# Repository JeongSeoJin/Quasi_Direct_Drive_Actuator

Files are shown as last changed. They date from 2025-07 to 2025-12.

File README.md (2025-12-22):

<script type="text/javascript" async
  src="https://cdnjs.cloudflare.com/ajax/libs/mathjax/2.7.7/MathJax.js?config=TeX-MML-AM_CHTML">
</script>
<script type="text/x-mathjax-config">
  MathJax.Hub.Config({
    tex2jax: {
      inlineMath: [['$','$'], ['\\(','\\)']],
      displayMath: [['$$','$$'], ['\\[','\\]']],
      processEscapes: true
    }
  });
</script>

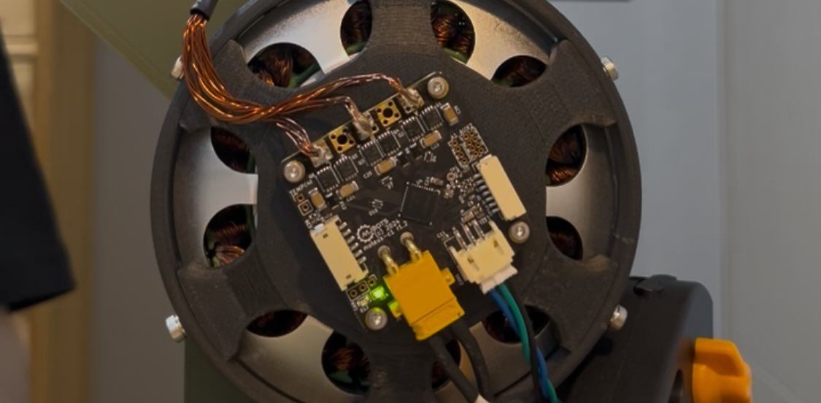
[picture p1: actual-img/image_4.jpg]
Actuator image 1


# Cycloidal QDD Actuator for Dynamic Robots

> *Note: This is an ongoing project. Please note that some sections, particularly '5. Control & Validation', are currently being documented. New test results and updates will be uploaded soon.*

[=> view this page in github with resources](https://github.com/JeongSeoJin/quasi-direct-drive-actuator)

Table of contents

- [1. Abstract](#1-abstract)
- [2. Actuator Design : Why Cycloidal QDD Actuator?](#2-actuator-design-why-qdd-actuator)
- [3. System Architecture & Components](#3-system-architecture--components)
- [4. Assembly](#4-assembly)
- [5. Control & Validation](#5-control--validation)
- [6. Limitations & Future Works](#6-limitations--future-works)
- [7. Credits](#7-credits)
- [8. References](#8-references)

---

## 1. Abstract
Rapid advancements in dynamic humanoid and quadruped robots have surged recently. However, high-performance actuators remain largely proprietary, restricting access for academic researchers and open-source communities. This project aims to democratize dynamic robotics by developing an open-source Quasi-Direct Drive (QDD) actuator tailored for mid-size humanoid robots.

Traditional high-ratio gearboxes suffer from poor back-drivability, low responsiveness and limited transmission transparency, making them unsuitable for safe Human-Robot Interaction (HRI) and uneven terrain locomotion. To address this, I propose a custom-designed QDD actuator featuring a 1:10 cycloidal reducer. This low-reduction architecture minimizes mechanical impedance, enabling back-drivable, high responsiveness and proprioceptive torque sensing via FOC algorithms without additional sensors.

The current prototype utilizes a 3D-printed and aluminium structure to ensure low cost and accessibility. Preliminary assessments estimate a maximum holding torque exceeding 7 Nm, with comprehensive performance verification currently underway. This work contributes to the robotic community by providing a scalable, affordable, and high-performance actuation solution.

  <table>
    <tr>
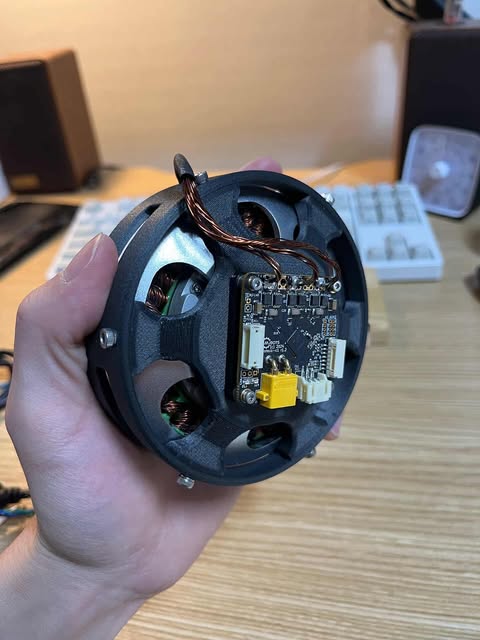
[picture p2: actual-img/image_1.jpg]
Actuator image 1
      <td></td>
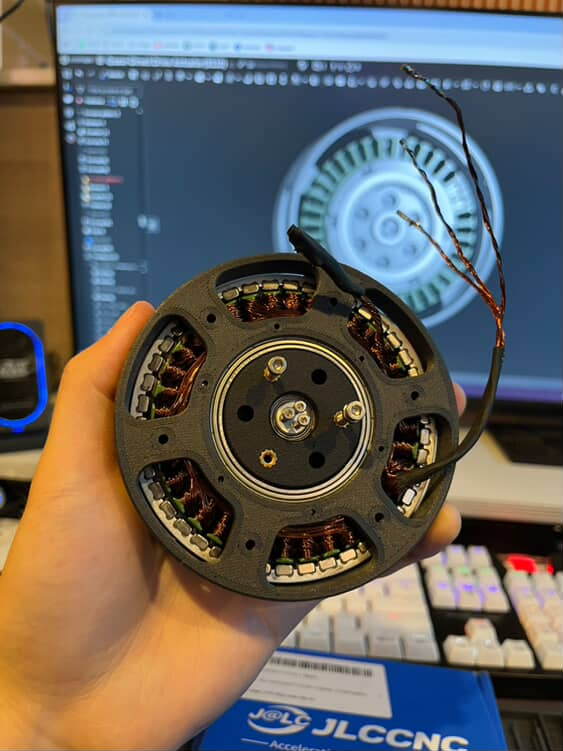
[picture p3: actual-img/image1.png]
Actuator image 2
      <td></td>
    </tr>
  </table>

---

## 2. Actuator Design: Why QDD Actuator?

### 2.1 The Limitations of Traditional Actuators

**Conventional robotic actuators** typically utilize high gear reduction ratios (e.g., 1:100 or higher) to amplify torque. However, this approach introduces significant drawbacks for dynamic robots.

A high gear ratio leads to **high mechanical impedance**, primarily due to increased friction and reflected inertia compared to low-ratio systems [[1]](#8-references).

This high impedance makes the motor response sluggish and susceptible to damage from sudden external impacts, as the actuators are too stiff to react compliantly. In other words, the actuator exhibits **poor back-drivability and low responsiveness**. Consequently, these properties hinder the robot's ability to interact safely with the environment, particularly in Human-Robot Interaction (HRI) scenarios or during dynamic locomotion.

As robots become more integrated into our daily lives, physical interaction and cooperation will become increasingly common. In these scenarios, traditional actuators pose a significant safety risk. Since robots with stiff actuators struggle to sense external forces [[2]](#8-references), they can unintentionally injure people due to their lack of compliance. Furthermore, regarding locomotion, such robots cannot flexibly adapt to unpredictable environments, such as rough or uneven terrain, leading to instability.

### 2.2 The QDD System Solution
To address these issues, I adopted a **Quasi-Direct Drive (QDD) architecture**. A QDD system typically features a low gear reduction ratio, ranging from 1:3 to 1:10. By positioning itself between Direct Drive (1:1) and traditional high-ratio drives (1:50 or higher), it combines the structural advantages of both systems.

The low gear ratio significantly minimizes friction and reflected inertia, rendering the actuator **inherently compliant**. This compliance ensures the system is smoothly back-drivable and highly responsive to external interactions, effectively mitigating the stiffness drawbacks of conventional actuators.

Consequently, this **improved back-drivability and responsiveness** enable the robot to safely interact with humans and flexibly adapt to uneven terrain during dynamic locomotion.

**At this point, a critical question arises:** "How can the actuator generate sufficient torque for dynamic motions with such a low gear ratio?" The following section details the design strategy used to resolve this trade-off.

### 2.3 Motor Design Optimization
To achieve high torque density suitable for a Quasi-Direct Drive (QDD) system, I focused on the geometric parameters of the motor. According to the motor design principles outlined in the MIT Cheetah research, the continuous torque generation capability ($\tau$) is approximated by the following equation:

$$\tau \propto \sigma \cdot l_{st} \cdot r_g^2$$

Where:
* **$\sigma$**: Shear stress density (magnetic flux density $\times$ current loading)
* **$l_{st}$**: Stack length of the motor
* **$r_g$**: Air gap radius

As shown in the equation, torque is linearly proportional to the stack length ($l_{st}$) but proportional to the **square of the air gap radius ($r_g^2$)**. This implies that increasing the motor diameter is significantly more efficient for boosting torque than increasing its length. Based on this principle, I selected a stator with a large diameter (8110 size) to maximize the air gap radius, thereby securing sufficient torque even with a low gear reduction ratio.

### 2.4 Transmission Selection: Why Cycloidal Reducer?

In dynamic legged locomotion, the actuator must withstand high impact loads caused by ground reaction forces. While **Harmonic Drives** are industry standards for zero-backlash precision, their flexible spline mechanism is notoriously fragile under shock loads.

Similarly, **Planetary Gearboxes**, though common, exhibit inherent backlash. It works well with aluminum gears, but becomes significantly fragile when 3D printed. In a 3D-printed planetary system, the stress concentrates on individual small gear teeth, making them prone to catastrophic failure under sudden external forces.

To ensure robustness, I selected a **Cycloidal Reducer** architecture. According to Sensinger's research, this mechanism distributes the load across multiple lobes simultaneously. This load-sharing capability provides significantly higher Shock Resistance compared to involute gears or fragile harmonic drives, making it the ideal candidate for a fully 3D-printed transmission [[3]](#8-references).

Furthermore, I optimized the internal mechanism for efficiency. While the outer profile uses a solid design for structural strength, the internal output mechanism operates based on Rolling Contact. By utilizing rolling pins for the output shaft transmission, I successfully minimized internal friction where structural fragility is less of a concern. This strategic design choice preserves the Back-drivability required for the QDD system while maintaining the robustness of the outer shell.

---

## 3. System Architecture & Components

### 3.1 Mechanical Design (Cycloidal Reducer)
A custom **Cycloidal Quasi-Direct Drive Actuator** is designed to ensure high torque density, compactness, and compliance.

I utilized Onshape 3D CAD to design a dual-disc cycloidal mechanism. The two cycloidal discs are arranged with a $180^\circ$ phase offset. This configuration effectively cancels out the radial forces and vibrations induced by the eccentric input shaft, ensuring smooth operation.

To maximize efficiency, I integrated rollers into the output pins. Unlike simple sliding contacts, these rollers minimize internal friction at the output stage, contributing to the system's back-drivability.

For the current prototype, the gears, shafts and rotor are manufactured from CNC-machined Aluminum to verify the design with a high strength-to-weight ratio. (Note: The final goal of this project is to optimize the design for a fully 3D-printed, low-cost actuator for dynamic robots.)

  <table>
    <tr>
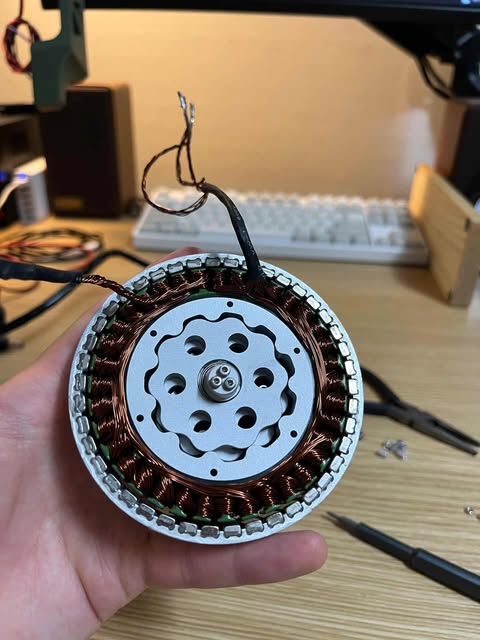
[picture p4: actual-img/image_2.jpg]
Actuator image 1
      <td></td>
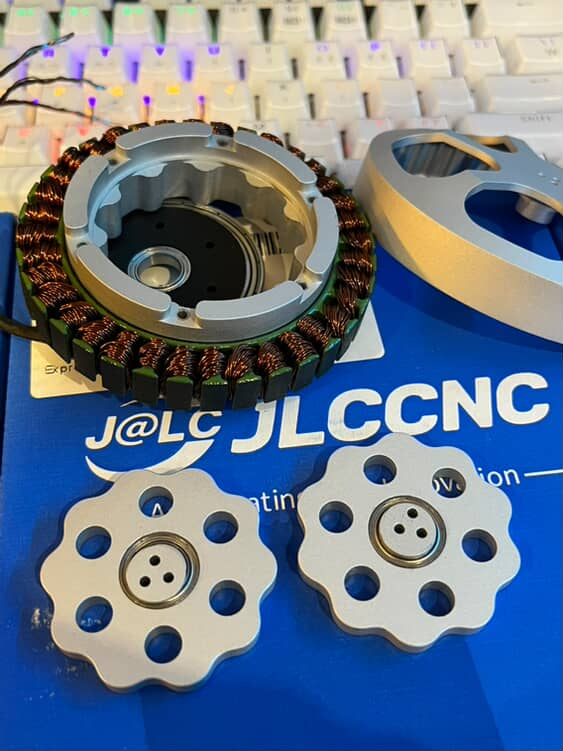
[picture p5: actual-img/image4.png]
Actuator image 2
      <td></td>
    </tr>
  </table>

### 3.2 Electromagnetic Design (Custom BLDC)

To optimize torque density within the compact housing, I integrated a **custom-built frameless Brushless DC (BLDC) motor** instead of using a standard motor.

For the stator, I utilized a standard 8110 stator core. To achieve the desired current capacity and fill factor, the stator was hand-wound using 0.4mm enameled copper wire. I applied a Wye (Star) termination with 6 parallel strands and 5 turns per tooth, following the optimal winding scheme calculated via open-source tools [[4]](#8-references).

The motor adopts a 36N42P configuration (36 slots, 42 poles) to maximize torque output. For the rotor, 42 N52-grade Neodymium magnets were installed. These magnets were precisely bonded using high-strength epoxy (JB Weld) in an alternating polarity pattern (N-S-N-S) to maximize magnetic flux density and ensure structural integrity under high rotation speeds. Crucially, the rotor geometry was optimized to achieve a minimal air gap of 0.5mm. This tight clearance maximizes the magnetic flux linkage between the rotor and stator, thereby significantly enhancing the electromagnetic force and overall torque efficiency.

### 3.3 Electronics & Sensors
For precise torque control and dynamic response, I integrated the **Moteus-c1 controller** (mjbots). This controller is widely adopted in the dynamic robotics community for its compact form factor and high bandwidth.

It implements **Field Oriented Control (FOC)**, which is essential for smooth torque generation and the proprioceptive capabilities mentioned earlier. With a wide input range (10-51V) and 20A peak phase current, it provides sufficient power capacity to drive the custom-wound 8110 stator to its full potential.

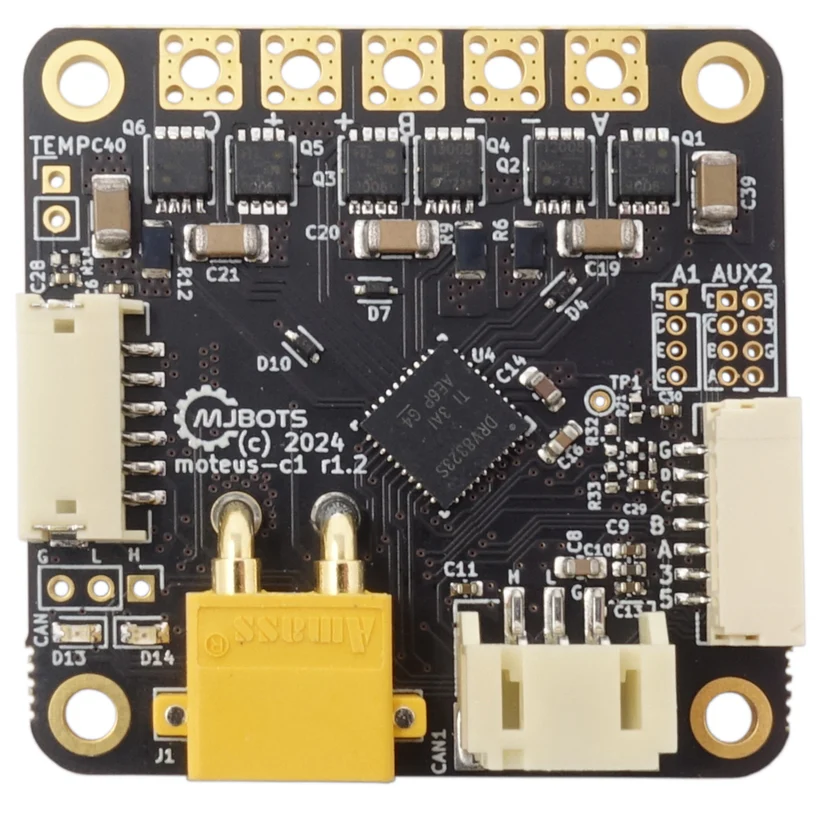
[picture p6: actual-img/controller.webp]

---

## 4. Assembly
Precise assembly is critical to minimize backlash and ensure the longevity of the reducer. I implemented distinct **tolerance strategies** based on the material properties of each component.

### 4.1 Bearing Installation & Fits
For the housing components printed in PA-CF12 (Carbon Fiber Nylon), I designed a 0.1mm interference fit. This accounts for the material's slight compliance and thermal shrinkage during printing, ensuring a secure press-fit without cracking the part.

Conversely, for the CNC-machined Aluminum parts, a tighter 0.02mm interference fit was applied due to the metal's rigidity. To prevent any micro-movements or slippage under high torque loads, I reinforced these metal-to-bearing interfaces with a thin application of JB Weld epoxy.

### 4.2 Output Mechanism
The output transmission relies on smooth rolling contact. I installed six M2x20mm stainless steel shafts to serve as the carrier pins. These shafts were precision-aligned to allow the external rollers to rotate freely, minimizing friction at the output stage while maintaining structural rigidity.

---

## 5. Control & Validation
preparing 

---

## 6. Limitations & Future Works
### 6.1 Limitations of the Current Prototype

Through the testing and assembly process, two primary limitations were identified regarding the actuator's performance and structural dynamics.

First, Suboptimal Magnetic Flux Path (Rotor Design)
The current rotor design does not incorporate a ferromagnetic back-iron or a Halbach array arrangement. Consequently, the magnetic flux is not effectively focused inward toward the stator, leading to flux leakage.

Since air-gap flux density directly correlates with torque generation, this lack of magnetic circuit optimization results in a lower torque density than theoretically possible. In future iterations, adding a steel back-iron will be essential to maximize torque output.

Second, Structural Rigidity of the Eccentric Shaft
The second issue lies in the assembly of the eccentric input shaft. Currently, it is constructed as a multi-part assembly fastened with bolts and nuts, rather than a single monolithic part. 

During operation, the strong radial magnetic attraction between the rotor and stator exerts significant force on the shaft. This force compromises the alignment of the multi-part shaft assembly, causing slight structural deflection. This misalignment leads to unwanted oscillation and vibration, particularly at higher rotational speeds. A monolithic (single-piece) shaft design is required to resolve this issue.

### 6.2 Future Works

Moving forward, I aim to integrate these custom QDD actuators into a mid-size bipedal robot to validate their performance in a complete system. The target platform will feature a total of 10 degrees of freedom (DoF), with 5 actuators allocated to each leg, specifically designed to handle dynamic walking tasks. This project will serve as a crucial step in verifying the scalability of my hardware design while providing a physical testbed for implementing advanced locomotion control algorithms.

---

## 7. Credits
* Design, Engineering and Documentation: [Seo Jin Jeong](https://jeongseojin.github.io/)
* Manufacturing Sponsor: [JLCCNC](https://jlccnc.com/)
* Motor Controller: [Moteus-c1 Controller (mjbots)](https://mjbots.com/products/moteus-c1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)
* Youtube : [Engineering SeoJin](http://www.youtube.com/@engineeringseojin)
* Instagram : [engineering.seojin_n.n](https://www.instagram.com/engineering.seojin_n.n?utm_source=ig_web_button_share_sheet&igsh=ZDNlZDc0MzIxNw==)

## 8. References

[1] S. Seok et al., "Design Principles for Energy-Efficient Legged Locomotion and Implementation on the MIT Cheetah Robot," in IEEE/ASME Transactions on Mechatronics, vol. 20, no. 3, pp. 1117-1129, June 2015, doi: 10.1109/TMECH.2014.2339013. 

[2] P. M. Wensing, A. Wang, S. Seok, D. Otten, J. Lang and S. Kim, "Proprioceptive Actuator Design in the MIT Cheetah: Impact Mitigation and High-Bandwidth Physical Interaction for Dynamic Legged Robots," in IEEE Transactions on Robotics, vol. 33, no. 3, pp. 509-522, June 2017, doi: 10.1109/TRO.2016.2640183.

[3] Sensinger, J. W. (February 9, 2010). "Unified Approach to Cycloid Drive Profile, Stress, and Efficiency Optimization." ASME. J. Mech. Des. February 2010; 132(2): 024503. https://doi.org/10.1115/1.4000832

[4] "bavaria-direct.co.za - Homebuilt Electric Motors," [Online]. Available: https://www.bavaria-direct.co.za/scheme/calculator/.

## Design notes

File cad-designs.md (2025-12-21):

## Overview

<div style="display:flex; flex-wrap:wrap; gap:8px;">
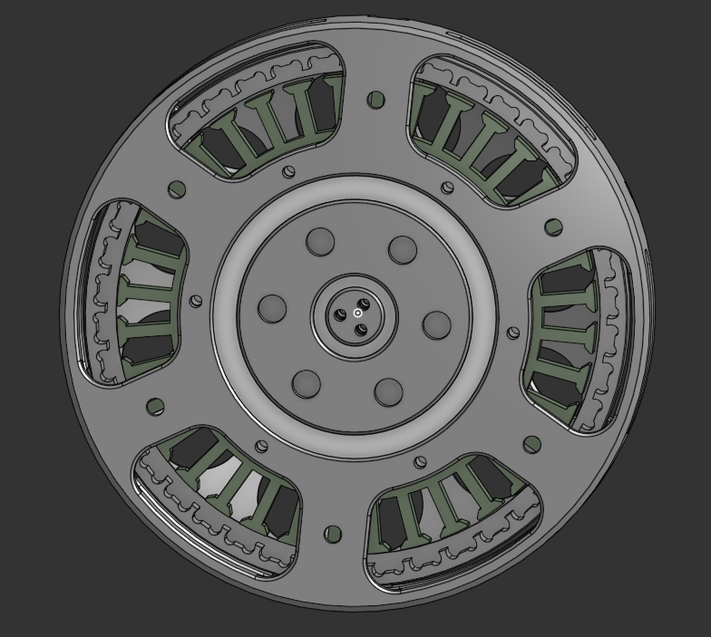
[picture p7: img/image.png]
overview1
  
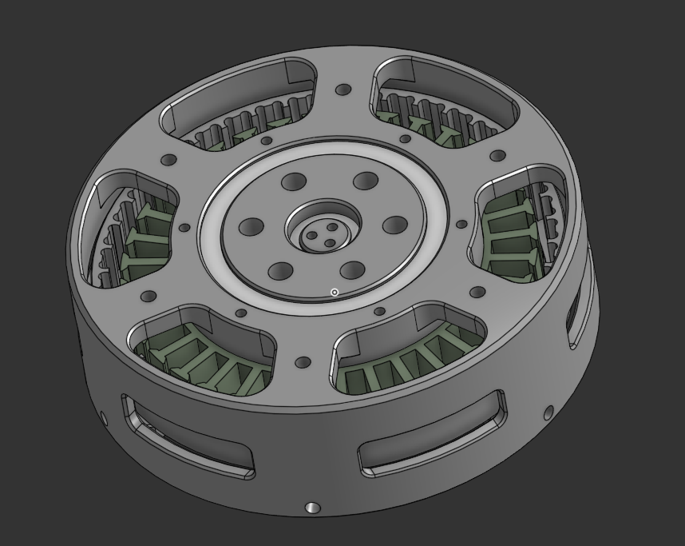
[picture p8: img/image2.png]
overview2
  
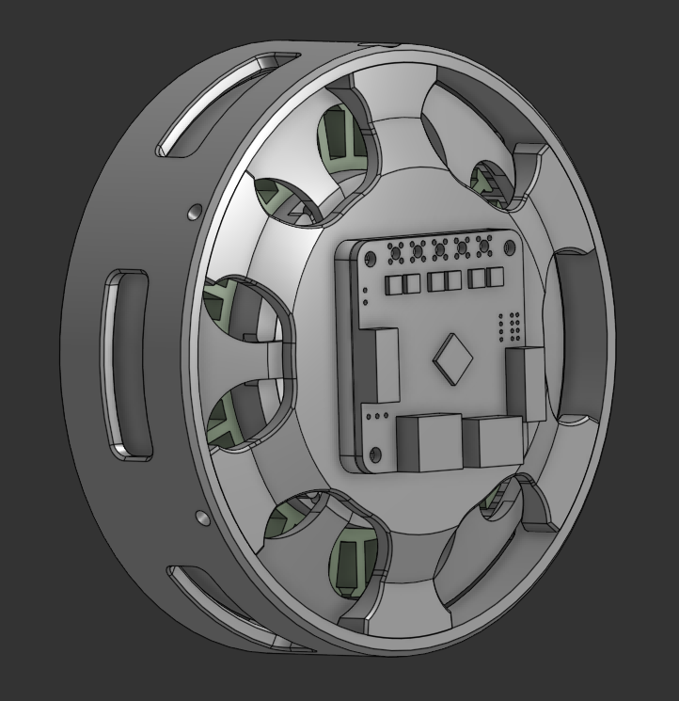
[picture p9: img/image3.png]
overview3
  
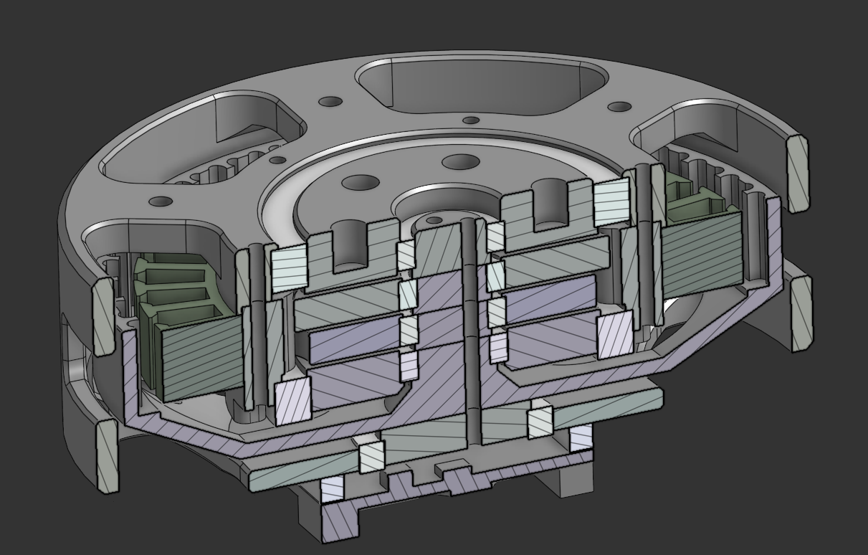
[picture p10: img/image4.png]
overview4
  
</div>

---

## Materials & finishes

### Housing — PA12-CF
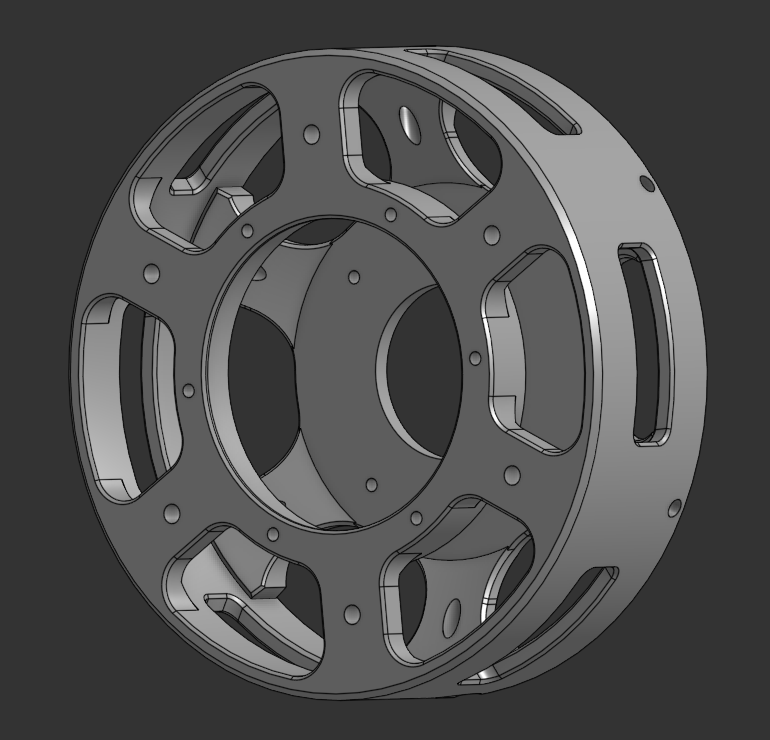
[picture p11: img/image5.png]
housing


### Gears — Aluminum 6061 (bead blasted + anodized)
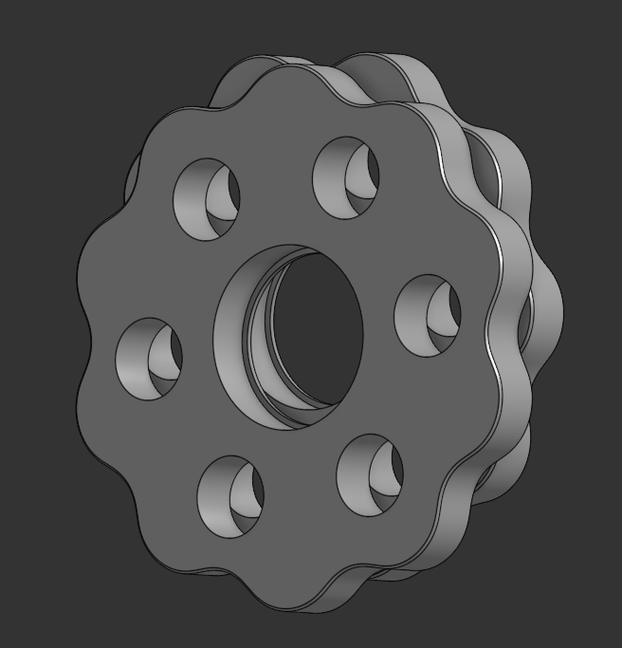
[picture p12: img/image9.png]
gears


### Input shaft & rotor — Aluminum 6061 (bead blasted + anodized)
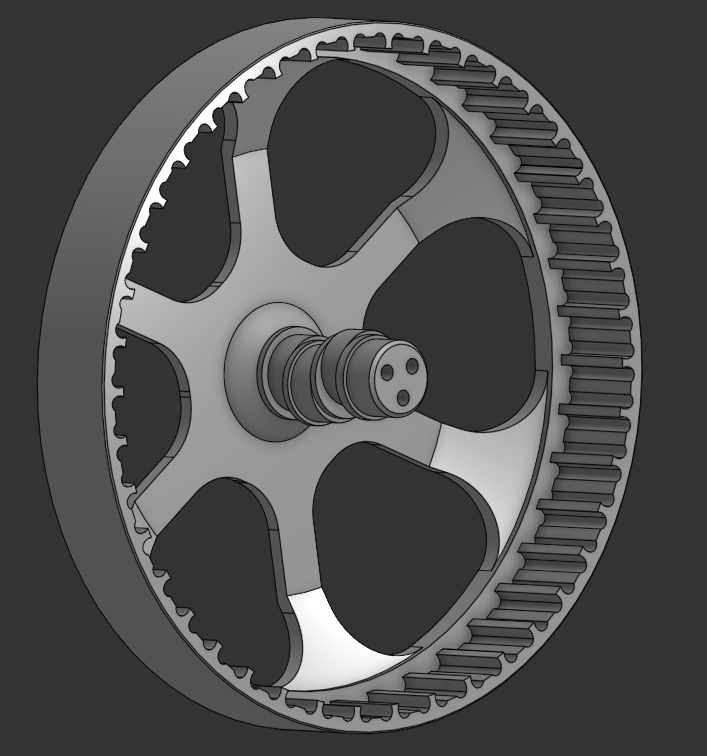
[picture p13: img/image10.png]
shaft1

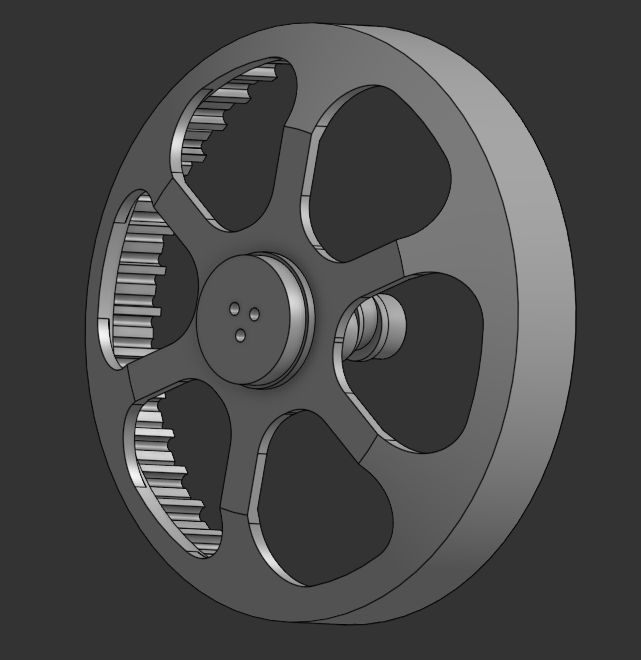
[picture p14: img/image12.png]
shaft2


### Output shaft — PA12-CF
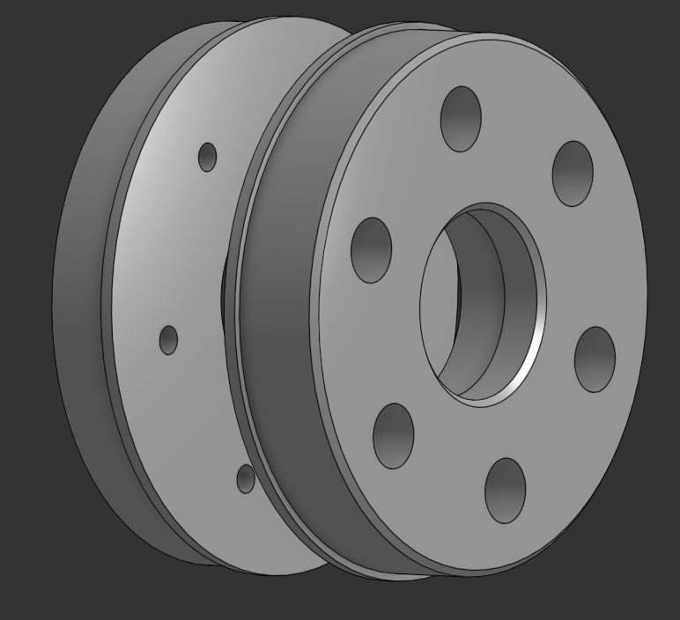
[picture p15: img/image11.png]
output-shaft


### Outer gear — PA12-CF or Aluminum 6061
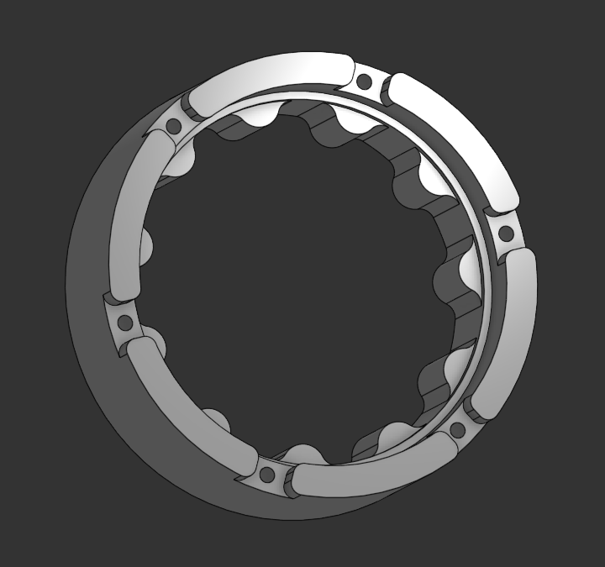
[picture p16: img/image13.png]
outer-gear


### Coupler — Housing to rotor(PLA)
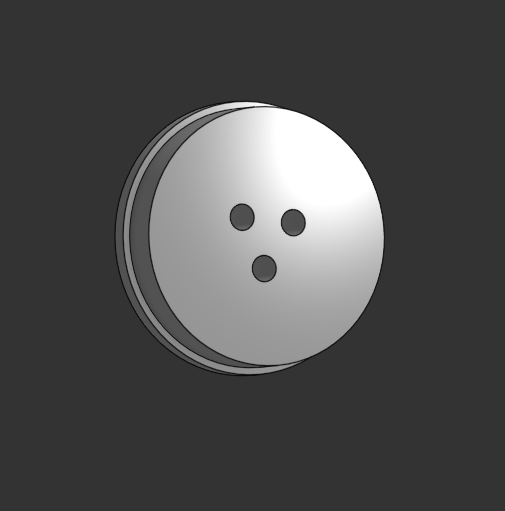
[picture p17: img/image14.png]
coupler


---

## Off-the-shelf parts
Common commercial parts used: bearings, stator, FOC controller, fasteners. See OFF_THE_SHELF_SPECIFICATIONS for part numbers and suppliers.

<div style="display:flex; gap:8px; flex-wrap:wrap;">
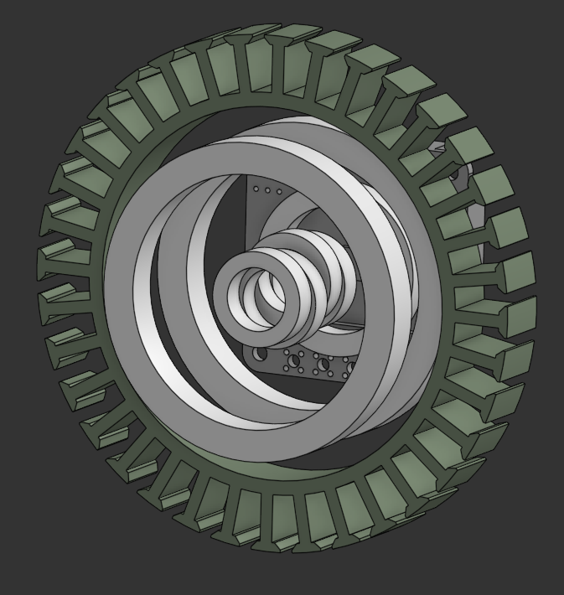
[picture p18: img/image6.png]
part1
  
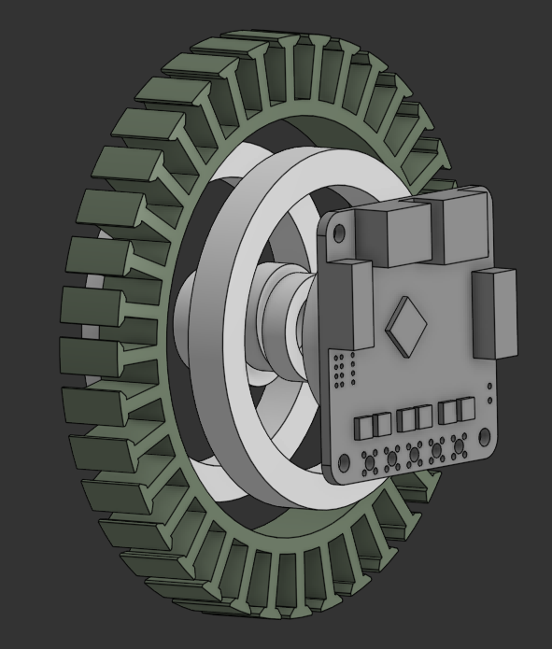
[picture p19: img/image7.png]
part2
  
</div>

---

## Assembly images
These are assembly images(I'm preparing for more details)

<div style="display:flex; flex-wrap:wrap; gap:8px;">
  assembly1
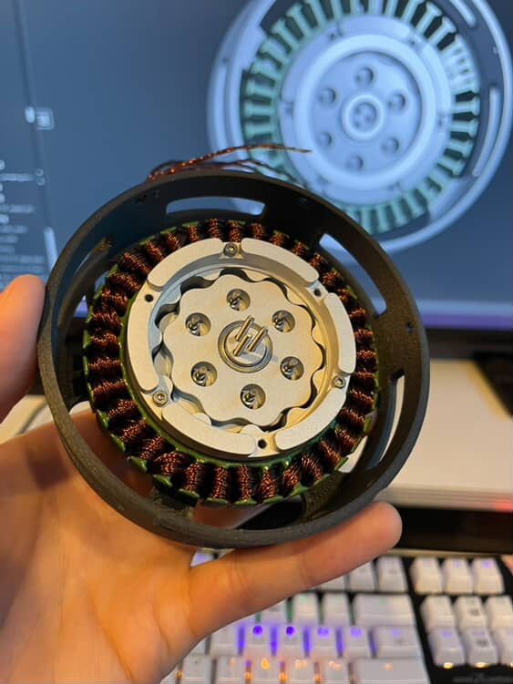
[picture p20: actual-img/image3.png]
assembly2
  
  assembly3
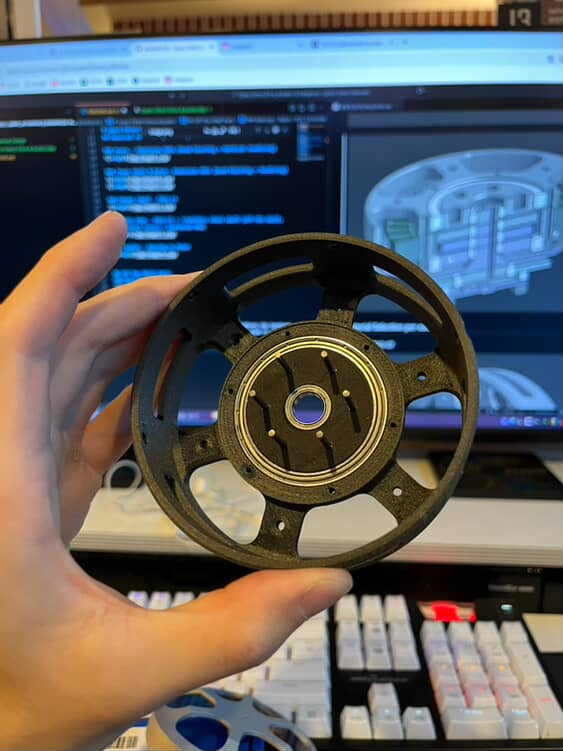
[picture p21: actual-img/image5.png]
assembly4
  
  assembly5
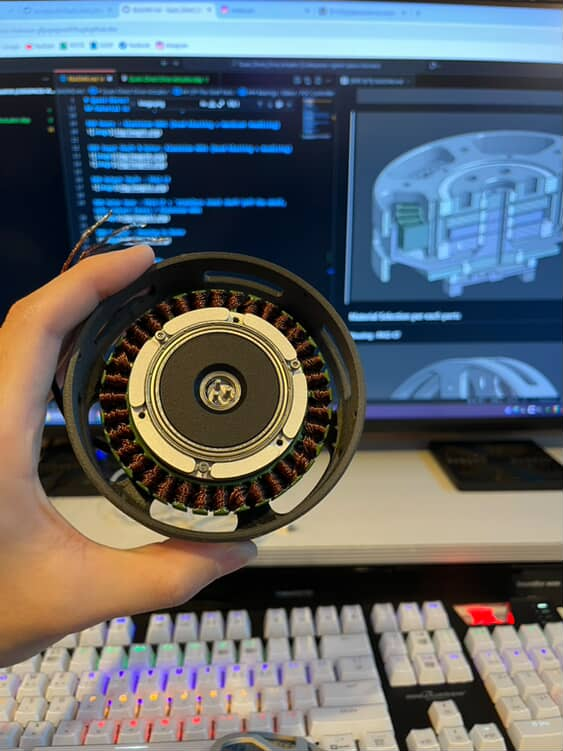
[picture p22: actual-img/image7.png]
assembly6
  
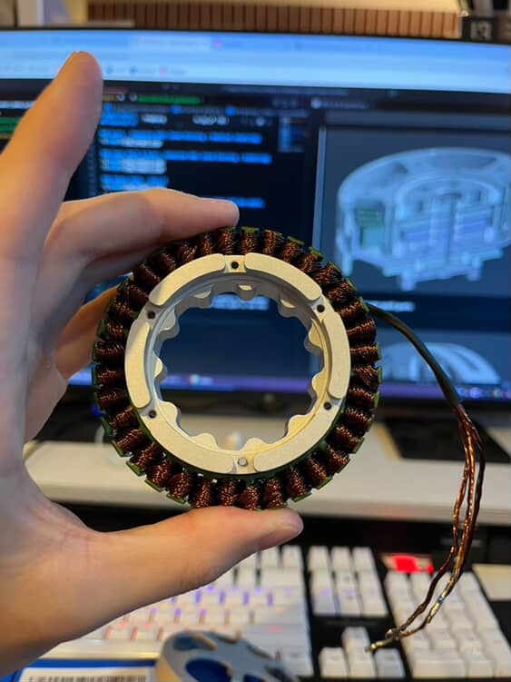
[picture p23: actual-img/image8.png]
assembly7
  
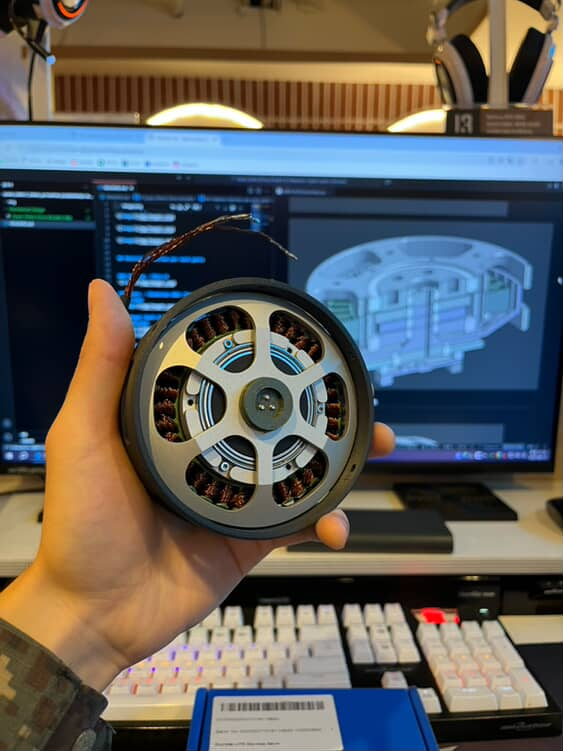
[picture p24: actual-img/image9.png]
assembly8
  
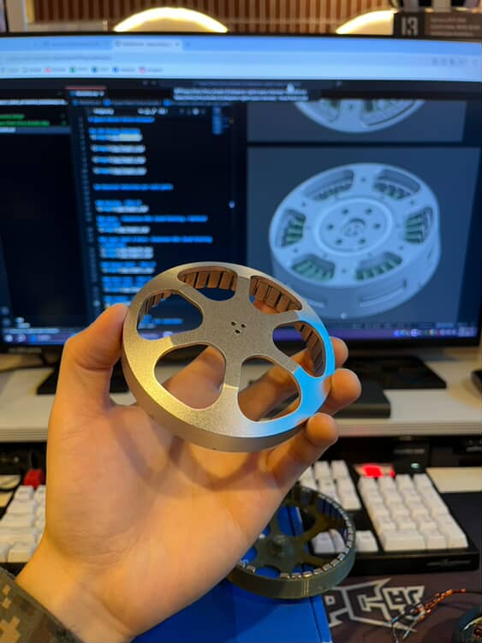
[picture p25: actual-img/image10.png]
assembly9
  
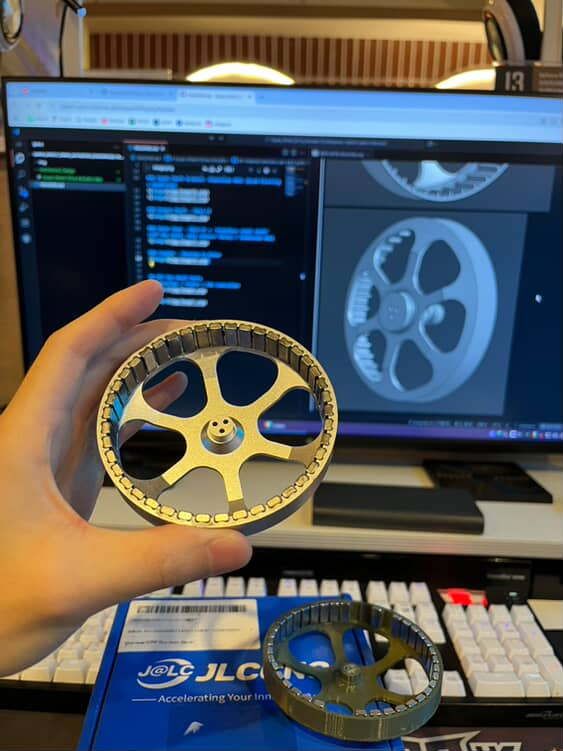
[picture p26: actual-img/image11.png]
assembly10
  
</div>

---

I keep developing my actuators. It's ongoing project. please stay tuned!

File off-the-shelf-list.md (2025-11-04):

# Off the shelf parts are listed in this file 

1. [8110 stator](https://ko.aliexpress.com/item/1005005460688806.html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) : (1EA)
2. [Bushing](https://ko.aliexpress.com/item/1005008259517878.html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) : D4xM2xL5(12EA)
3. [Shaft](https://ko.aliexpress.com/item/1005007023343232.html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) : M2, 20mm(6EA)
4. [Bearings](https://ko.aliexpress.com/item/4000909605390.html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,scm-url:1007.14452.398466.0,pvid:2f273fae-4f10-467f-b87d-71dfd033900c,tpp_buckets:668%232846%238108%231977&pdp_ext_f=%7B%22order%22%3A%22285%22%2C%22eval%22%3A%221%22%2C%22sceneId%22%3A%2230050%22%2C%22fromPage%22%3A%22recommend%22%7D&pdp_npi=6%40dis%21KRW%213466%211908%21%21%212.34%211.29%21%40210156fc17622595700133547e27dc%2112000028447926012%21rec%21KR%212150707868%21X%211%210%21n_tag%3A-29919%3Bd%3Ac599d003%3Bm03_new_user%3A-29895%3BpisId%3A5000000192578935&utparam-url=scene%3ApcDetailTopMoreOtherSeller%7Cquery_from%3A%7Cx_object_id%3A4000909605390%7C_p_origin_prod%3A&search_p4p_id=202511040432500535210504583292530167_0) : 40x50x6mm(2EA), 20x27x4mm(1EA), 10x15x4mm(4EA)
5. [Moteus Controller C1](https://mjbots.com/products/moteus-c1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) : (1EA)
6. [Enameled copper wire](https://ko.aliexpress.com/item/1005001704276751.html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,scm-url:1007.14452.398466.0,pvid:4f8f4469-c6f8-42d0-87eb-8b017c4bf703,tpp_buckets:668%232846%238108%231977&pdp_ext_f=%7B%22order%22%3A%2215%22%2C%22eval%22%3A%221%22%2C%22sceneId%22%3A%2230050%22%2C%22fromPage%22%3A%22recommend%22%7D&pdp_npi=6%40dis%21KRW%2121369%2117950%21%21%21102.83%2186.38%21%4021015b7d17622599050302774e0a10%2112000017224525099%21rec%21KR%212150707868%21X%211%210%21n_tag%3A-29919%3Bd%3Ac599d003%3Bm03_new_user%3A-29895&utparam-url=scene%3ApcDetailTopMoreOtherSeller%7Cquery_from%3A%7Cx_object_id%3A1005001704276751%7C_p_origin_prod%3A&search_p4p_id=202511040438250676566686109481710543_2) : 0.41mm(1EA)
7. [Permanet magnets](https://ko.aliexpress.com/item/1005010189199719.html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) : N52 12x5x3mm(42EA)

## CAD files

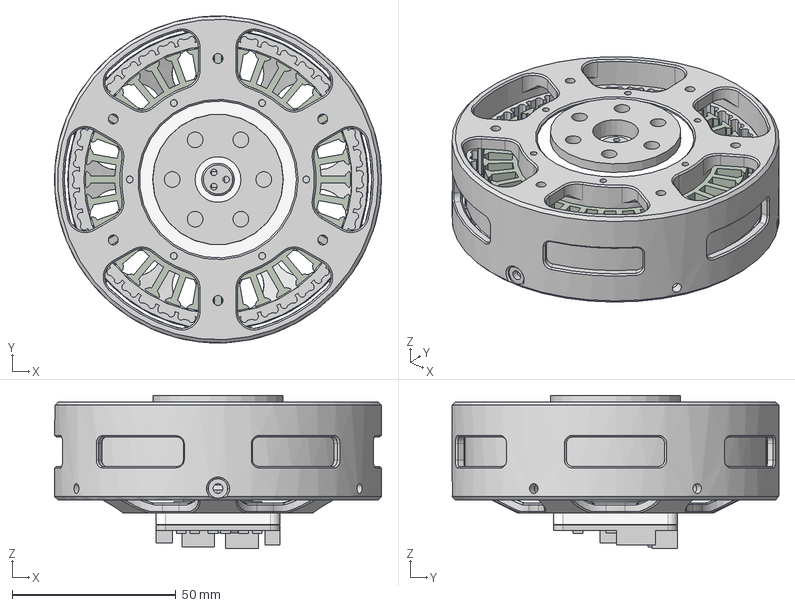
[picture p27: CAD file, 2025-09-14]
actuator-cad-file/Quasi-Direct Drive Actuator.step
100.0 x 100.0 x 46.9 mm
3dp_shaft
cnc_bldc_rotor
bearing x 7
PA12-CF_body_top
PA12-CF_body_bottom
cnc_disk_top
moteus-c1 r1.2 simple
cnc_body_ring
cnc_input_shaft3
off_the_shelf_bldc_stator
PA12-CF_output_shaft_top
cnc_disk_bottom
cnc_input_shaft1
3dp_cotroller_spacer
PA12-CF_ouput_shaft_bottom
cnc_input_shaft2

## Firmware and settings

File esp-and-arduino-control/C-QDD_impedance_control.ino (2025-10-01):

/**
 * 위치 기반 토크 제어 (전류제어 FOC) 예시 코드
 * 
 * [개념]
 *  - 모터의 현재 각도(shaft_angle, [rad])와 목표 각도(theta_desired, [rad])를 비교해
 *    오차(angleError)를 구한다.
 *  - 오차 * Kp ([A/rad]) = 토크 지령 전류(I_q_ref, [A])를 계산한다.
 *  - SimpleFOC는 FOC Current 모드(TorqueControlType::foc_current)에서 이 전류를
 *    실제로 모터의 q축 전류(I_q)로 만들기 위해 PWM을 제어한다.
 * 
 *  => motor.target = I_q_ref (단위: [A])
 *  => 실제 토크 T [N·m] = Kt [N·m/A] × I_q [A]
 */

// This source code is for a proprioceptive actuator v2. torque sensing using q-axis current sensing

#include <SimpleFOC.h>  // SimpleFOC 라이브러리
#include <math.h>

// ============================ 핀 매핑 설정 ============================
// DRV8302 보드 핀 연결 (기본 예시)
#define INH_A    14     // 하이사이드 PWM A
#define INH_B    27     // 하이사이드 PWM B
#define INH_C    26     // 하이사이드 PWM C
#define EN_GATE  13     // 드라이버 활성화
#define M_PWM    33     // 3pwm 모드 설정
#define M_OC     25     // 오버커런트 보호
#define OC_ADJ   32     // 오버커런트 조정
#define OC_GAIN  5      // DRV8302 내부 증폭기 게인 선택 핀

// 로사이드 전류 센싱 핀 (ESP32 ADC 핀)
#define IOUTA 4         // ADC2_CH0
#define IOUTB 12        // ADC2_CH5
#define IOUTC 15        // ADC2_CH3

// ============================= 모터, 드라이버, 센서 =============================

// 1) 모터 객체
//  - BLDCMotor( pole_pairs ): pole_pairs = 극수(pole) / 2
//  - 예: 22극 모터 -> pole_pairs=11
BLDCMotor motor = BLDCMotor(21);

// 2) 드라이버 객체
BLDCDriver3PWM driver = BLDCDriver3PWM(INH_A, INH_B, INH_C, EN_GATE);

// 3) 로사이드 전류센싱
//  - 샨트저항: 0.005Ω
//  - 증폭기 게인: 12.22 V/V (DRV8302 내부 증폭 + 외부 회로에 따라 측정)
LowsideCurrentSense cs = LowsideCurrentSense(0.005f, 12.22f, IOUTA, IOUTB, IOUTC);

// 4) 엔코더 (AS5600 I2C 예시)
MagneticSensorI2C encoder = MagneticSensorI2C(AS5600_I2C);

// 5) 시리얼 커맨드 인터페이스
Commander command = Commander(Serial);
// void onMotor(char* cmd) { command.motor(&motor, cmd); }

// ============================= 제어용 전역 변수 =============================
// 목표 각도 [rad]
float theta_desired = 0.0f;  
// 위치 오차 → 전류로 바꿀 때 사용하는 비례이득 Kp [A/rad]
// 예) Kp=1.0 -> 오차 1rad당 q축전류 1A
float Kp = 2.0f; // max : 5.0
float Cd = 0.2f; // max : 0.2
float max_speed = 60.0f;

float Kt = 60 / (2 * PI * 380);

// Commander에서 theta_desired, Kp를 설정하기 위한 함수
void doRefAngle(char* cmd) { command.scalar(&theta_desired, cmd); }
void doKp(char* cmd)       { command.scalar(&Kp, cmd); }
void doCd(char* cmd)       { command.scalar(&Cd, cmd); }

void setup() {
  // ========== 시리얼 초기화 ==========
  Serial.begin(115200);
  // SimpleFOC 디버그 활성화(옵션)
  SimpleFOCDebug::enable(&Serial);

  // ========== 센서 초기화 ==========
  encoder.init();           // I2C 기반 AS5600 초기화
  motor.linkSensor(&encoder);

  // ========== DRV8302 관련 핀 설정 ==========
  pinMode(M_OC, OUTPUT);
  digitalWrite(M_OC, LOW);
  pinMode(M_PWM, OUTPUT);
  digitalWrite(M_PWM, HIGH);
  pinMode(OC_ADJ, OUTPUT);
  digitalWrite(OC_ADJ, HIGH);
  pinMode(OC_GAIN, OUTPUT);
  digitalWrite(OC_GAIN, LOW); // LOW 상태에서 특정 게인 (약 10~12배)

  // ========== 드라이버 설정 ==========
  driver.voltage_power_supply = 12;   // 드라이버 공급전압 [V]
  // driver.pwm_frequency = 15000;       // PWM 주파수 [Hz]
  driver.init();
  motor.linkDriver(&driver);

  // ========== 전류센서 설정 ==========
  cs.linkDriver(&driver);
  
  // ========== 모터 기본 파라미터 ==========
  // FOC 정렬 시 사용하는 전압(각도 캘리브레이션)
  motor.voltage_sensor_align = 0.5f; // [V]
  
  // ========== 핵심: 전류제어(FOC) 설정 ==========
  // 1) 토크제어 모드: foc_current => q축 전류를 직접 제어함
  motor.torque_controller = TorqueControlType::foc_current;
  
  // 2) MotionControlType::torque => motor.target = q축전류(A)
  motor.controller = MotionControlType::torque;
  
  // 3) motion_downsample: 속도/각도 루프를 생략하거나 간소화 (여기서는 0.0)
  motor.motion_downsample = 0.0;

  // ========== PID / LPF 설정 (주로 내부 PI 전류 루프) ==========
  // 전류 i_q 제어
  motor.PID_current_q.P  = 0.05f;   // [V/A] (내부 환산 게인)
  motor.PID_current_q.I  = 0.0f; // [V/(A·s)]
  motor.LPF_current_q.Tf = 0.04f;  // [s]

  // 전류 i_d 제어
  motor.PID_current_d.P  = 0.05f;   // [V/A]
  motor.PID_current_d.I  = 0.0f; // [V/(A·s)]
  motor.LPF_current_d.Tf = 0.04f;  // [s]

  // 속도/각도 제어(지금 안씀)도 일단 기본값 설정
  motor.PID_velocity.P  = 0.1f; 
  motor.PID_velocity.I  = 0.0f;  
  motor.LPF_velocity.Tf = 0.001f;
  motor.P_angle.P       = 5.0f;  
  motor.LPF_angle.Tf    = 0.0f;

  // ========== 제한값 ==========
  // 최대 속도 [rad/s] (토크모드이지만 안전 차원)
  motor.velocity_limit = 10.0f; 
  // FOC에서 인가할 전압의 최대치 [V]
  motor.voltage_limit  = 5.0f;  
  // 최대 전류 제한 [A]
  // -> motor.target이 이 값을 초과 못하도록 내부 보호
  motor.current_limit  = 5.0f;   

  // ========== 모니터링 설정 ==========
  motor.useMonitoring(Serial);
  // D축, Q축 전류 모니터링
  motor.monitor_variables = _MON_CURR_Q | _MON_CURR_D; // q가 토크에 관여, D는 0에 가까워져 있어야함. 
  // 출력 주기 : loopFOC()가 n번 실행될 때마다 한번씩 출력
  motor.monitor_downsample = 100;

  // ========== 모터 초기화 ==========
  motor.init();   // 드라이버, 센서 설정에 맞춰 모터구조 초기 설정
  cs.init();      // 전류센싱 초기화
  // DRV8302는 내부적으로 게인이 반전돼있는 경우가 있어 -1 곱
  cs.gain_a *= -1;
  cs.gain_b *= -1;
  cs.gain_c *= -1;
  motor.linkCurrentSense(&cs);

  // ========== FOC align & start ==========
  // 실제 모터에 전압을 인가하여 엔코더 0점 찾고, d/q 축 정렬
  motor.initFOC();

  // ========== Commander (시리얼 명령) ==========
  // command.add('M', onMotor, "motor");
  command.add('R', doRefAngle, "ref angle [rad]");
  command.add('K', doKp, "Kp [A/rad]");
  command.add('C', doCd, "Cd [A/rad]");

  Serial.println(F("FOC Current-based Torque Control (Position-based)"));
  Serial.println(F(" - R: set target angle [rad]"));
  Serial.println(F(" - K: set Kp [A/rad] (proportional gain)"));
  Serial.println(F(" motor.target will be I_q [A] in torque mode.\n"));

  _delay(1000);
}

void loop() {
  // ========== 1) FOC 알고리즘 업데이트 ==========
  //   - 센서 위치 갱신, d/q 전류 측정 및 PID 계산 등
  motor.loopFOC();

  // ========== 2) 위치 오차 계산 ==========
  //   - 엔코더 각도 [rad]
  float theta = motor.shaft_angle;
  float dtheta = motor.shaft_velocity;
  //   - theta_desired [rad], currentAngle [rad]
  // float angleError = theta_desired - currentAngle;  // [rad]

  // ========== 3) 토크 전류 지령 (Iq_ref) 계산 ==========
  //   - Kp [A/rad] * angleError [rad] = Iq_ref [A]
  float Iq_ref = Kp * (theta_desired - theta) -Cd * dtheta;

  // ========== 4) 모터에 q축 전류 지령 전송 ==========
  //   - torque 모드이므로 motor.target = Iq_ref
  //   - motor.target 단위: [A]

  float output_torque = 10 * Kt * motor.current.q;
  // Serial.println(output_torque);
  // Serial.println(motor.current.q); // 실제 q축 전류

  motor.target = Iq_ref; // [A] foc_current제어이기 때문에 target값이 q축 전류이다.

  // ========== 5) FOC 업데이트 (PWM 출력) ==========
  motor.move();

  // ========== 6) 모니터링 ==========
  motor.monitor();

  // ========== 7) 시리얼 명령 처리 ==========
  command.run();
}

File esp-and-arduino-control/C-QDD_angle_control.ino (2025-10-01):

/**
 *
 * Position/angle motion control example
 * Steps:
 * 1) Configure the motor and magnetic sensor
 * 2) Run the code
 * 3) Set the target angle (in radians) from serial terminal
 *
 */
#include <SimpleFOC.h>

// magnetic sensor instance - SPI
// MagneticSensorSPI sensor = MagneticSensorSPI(AS5147_SPI, 10);
// magnetic sensor instance - MagneticSensorI2C
MagneticSensorI2C sensor = MagneticSensorI2C(AS5600_I2C);
// magnetic sensor instance - analog output
// MagneticSensorAnalog sensor = MagneticSensorAnalog(A1, 14, 1020);

// BLDC motor & driver instance
BLDCMotor motor = BLDCMotor(21);
#define INH_A    14     // 하이사이드 PWM A
#define INH_B    27     // 하이사이드 PWM B
#define INH_C    26     // 하이사이드 PWM C
#define EN_GATE  13     // 드라이버 활성화
#define M_PWM    33     // 3pwm 모드 설정
#define M_OC     25     // 오버커런트 보호
#define OC_ADJ   32     // 오버커런트 조정
#define OC_GAIN  5      // DRV8302 내부 증폭기 게인 선택 핀

// 로사이드 전류 센싱 핀 (ESP32 ADC 핀)
#define IOUTA 4         // ADC2_CH0
#define IOUTB 12        // ADC2_CH5
#define IOUTC 15        // ADC2_CH3// Stepper motor & driver instance
//StepperMotor motor = StepperMotor(50);
//StepperDriver4PWM driver = StepperDriver4PWM(9, 5, 10, 6,  8);

BLDCDriver3PWM driver = BLDCDriver3PWM(INH_A, INH_B, INH_C, EN_GATE);


// angle set point variable
float target_angle = 0;
// instantiate the commander
Commander command = Commander(Serial);
void doTarget(char* cmd) { command.scalar(&target_angle, cmd); }

void setup() {

  // use monitoring with serial 
  Serial.begin(115200);
  // enable more verbose output for debugging
  // comment out if not needed
  SimpleFOCDebug::enable(&Serial);

  pinMode(M_OC, OUTPUT);
  digitalWrite(M_OC, LOW);
  pinMode(M_PWM, OUTPUT);
  digitalWrite(M_PWM, HIGH);
  pinMode(OC_ADJ, OUTPUT);
  digitalWrite(OC_ADJ, HIGH);
  pinMode(OC_GAIN, OUTPUT);
  digitalWrite(OC_GAIN, LOW); // LOW 상태에서 특정 게인 (약 10~12배)


  // initialise magnetic sensor hardware
  sensor.init();
  // link the motor to the sensor
  motor.linkSensor(&sensor);

  // driver config
  // power supply voltage [V]
  driver.voltage_power_supply = 24; 
  driver.init();
  // link the motor and the driver
  motor.linkDriver(&driver);

  motor.voltage_sensor_align = 0.5f; // [V]

  // choose FOC modulation (optional)
  motor.foc_modulation = FOCModulationType::SpaceVectorPWM;

  // set motion control loop to be used
  motor.controller = MotionControlType::angle;

  // contoller configuration
  // default parameters in defaults.h

  // velocity PI controller parameters
  motor.PID_velocity.P = 0.2f;
  motor.PID_velocity.I = 0;
  motor.PID_velocity.D = 0;
  // maximal voltage to be set to the motor
  motor.voltage_limit = 10;

  // velocity low pass filtering time constant
  // the lower the less filtered
  motor.LPF_velocity.Tf = 0.01f;

  // angle P controller
  motor.P_angle.P = 4;
  // maximal velocity of the position control
  motor.velocity_limit = 25;
  
  // comment out if not needed
  motor.useMonitoring(Serial);


  // initialize motor
  motor.init();
  // align sensor and start FOC
  motor.initFOC();

  // add target command T
  command.add('T', doTarget, "target angle");

  Serial.println(F("Motor ready."));
  Serial.println(F("Set the target angle using serial terminal:"));
  _delay(1000);
}


void loop() {

  // main FOC algorithm function
  // the faster you run this function the better
  // Arduino UNO loop  ~1kHz
  // Bluepill loop ~10kHz
  motor.loopFOC();

  // Motion control function
  // velocity, position or voltage (defined in motor.controller)
  // this function can be run at much lower frequency than loopFOC() function
  // You can also use motor.move() and set the motor.target in the code
  motor.move(target_angle);


  // function intended to be used with serial plotter to monitor motor variables
  // significantly slowing the execution down!!!!
  // motor.monitor();

  // user communication
  command.run();
}

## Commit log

2025-07-30 Add:images of CAD Update:README.md
2025-09-14 Add: Mechanical_CAD_Design Add:Mechanical Assembly img
    [Quasi-Direct Drive Actuator.step]
2025-12-14 Add qdd-actuator.md file
2025-12-14 Add layout and title to qdd-actuator.md
    Add front matter to qdd-actuator.md for layout and title.
2025-12-14 Remove layout and title from qdd-actuator.md
    Removed layout and title from the QDD Actuator markdown file.
